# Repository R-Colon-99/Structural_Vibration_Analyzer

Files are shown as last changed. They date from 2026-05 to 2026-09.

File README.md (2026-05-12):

# Structural Vibration Analyzer

Low-cost multi-sensor structural vibration analysis platform using ESP32 and MEMS accelerometers for educational and experimental mechanical vibration studies.

---

# Overview

This project focuses on the development of a portable and affordable vibration-analysis system capable of measuring and analyzing structural vibration using low-cost MEMS accelerometers.

The system is designed primarily for:
- Mechanical vibration experimentation
- Educational laboratory use
- Structural response analysis
- Frequency-domain analysis using FFT
- Comparative sensor studies

The project currently uses multiple MPU6050 accelerometers connected to an ESP32 microcontroller through a PCA9548A I2C multiplexer.

---

# Objectives

- Develop a low-cost vibration analysis platform
- Measure structural vibration at multiple locations simultaneously
- Perform FFT analysis on acceleration data
- Compare structural vibration transmission between locations
- Investigate the limitations of low-cost MEMS sensors
- Create an accessible educational platform for vibration analysis

---

# Current Features

- ESP32-based data acquisition
- Support for 3 simultaneous MPU6050 sensors
- PCA9548A I2C multiplexer integration
- Binary serial data transmission
- Python-based logger and analyzer
- FFT analysis for X, Y, and Z axes
- Comparative FFT overlays between sensors
- Automatic graph generation and export
- Organized raw and processed data workflow

---

# Experimental Setup

Three accelerometers are mounted at different structural locations:

| Sensor | Location |
|---|---|
| S1 | Printer base/frame |
| S2 | Upper structural frame |
| S3 | Print head/extruder |

All sensors are rigidly mounted using screw-fastened brackets to improve measurement consistency and reduce mounting-induced vibration artifacts.

The current primary test platform is an Elegoo Centauri Carbon 3D printer.

---

# Hardware Used

- ESP32 Development Board
- MPU6050 Accelerometers (x3)
- PCA9548A I2C Multiplexer
- Rigid sensor mounting brackets
- USB Serial Communication
- Optional MicroSD module (future integration)

---

# Software Stack

- PlatformIO
- VS Code
- Python
- NumPy
- Matplotlib
- PySerial

---

# Future Work

- SD card standalone logging
- Wireless monitoring interface
- Higher-rate acquisition systems
- ADXL355 sensor integration
- Modal analysis implementation
- Natural frequency estimation tools
- Comparison with industrial accelerometers
- Real-time web dashboard visualization

---

# Author

Raúl Colón  
Mechanical Engineering Student  
Universidad Ana G. Méndez

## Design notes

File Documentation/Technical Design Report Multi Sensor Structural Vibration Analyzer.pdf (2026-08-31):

### Technical Design Report: Multi-Sensor Structural Vibration Analyzer

1. Executive Summary
In the domain of structural health monitoring (SHM), high-precision vibration analysis is the cornerstone of life-cycle assessment for critical infrastructure. Modern engineering demands high-fidelity data to detect infinitesimal modal shifts in bridges and industrial assets before they progress to catastrophic failure. This report outlines a hardware architecture that achieves professional-grade results—comparable to costly, proprietary DAQ systems—by utilizing a highly integrated, cost-effective embedded ecosystem. By shifting the paradigm from expensive centralized hardware to distributed, scalable sensing nodes, this architecture democratizes real-time frequency-domain analysis.The system synthesizes the computational power of the ESP32 System-on-Chip (SoC) with an array of MPU-6050 Micro-Electro-Mechanical Systems (MEMS) sensors. To overcome the physical limitations of I2C address bus contention, the design incorporates a TCA9548A/PCA9548A multiplexer, allowing the controller to interface with up to eight independent sensor nodes. The core operational objective is the maintenance of a deterministic, high-speed raw data stream to a host computer. By offloading the computationally intensive Fast Fourier Transform (FFT) to a host environment, the embedded system remains focused on precise temporal alignment and signal integrity, providing a blueprint for modern structural diagnostics.
2. Hardware Architecture & System Integration
The efficacy of a structural analyzer is dictated by its ability to resolve timing at the microsecond level while managing substantial data throughput. Selecting components that balance high-speed internal buffering with robust communication protocols is essential to meet the rigorous sampling requirements of civil engineering applications.

The ESP32 Processing Core
The heart of the system is the ESP32 Series SoC, featuring the Xtensa® 32-bit dual-core LX6 microprocessor. Running at a clock frequency of 240 MHz, this dual-core architecture is strategically utilized through "Core Pinning." In this configuration, the sampling Interrupt Service Routine (ISR) is pinned to Core 1 to ensure deterministic I2C polling, while Core 0 handles the non-deterministic overhead of the Wi-Fi or Bluetooth v4.2 (including BR/EDR and Bluetooth LE) stacks.
- Memory and Throughput: The 520 KB on-chip SRAM facilitates large sample buffers, which are essential for preventing data loss during burst transmissions. The system utilizes dedicated memory access pathways and the ESP32’s internal bus architecture to move data from the I2C peripheral to SRAM with minimal CPU intervention, maximizing the cycles available for real-time conditioning.
- Power Domain Configuration: To ensure logic level compatibility with the sensing array, the internal LDO (VDD_SDIO) must be configured for 3.3V operation. This is achieved by ensuring the MTDI strapping pin is held LOW (0) during the boot sequence, aligning the VDD_SDIO power domain with the VDD3P3_RTC voltage.

MPU-6050 Inertial Measurement Unit
The MPU-6050 provides 6-axis motion tracking, integrating a 3-axis accelerometer and a 3-axis gyroscope. For structural monitoring, the sensor’s 1024-byte FIFO buffer is a critical asset; it allows for continuous data accumulation even when the I2C bus is temporarily
occupied by the multiplexer switching logic.| Accelerometer Range | Sensitivity (LSB/g) |
Primary Application || ------ | ------ | ------ || ±2g | 16,384 | Seismic & Modal Bridge Analysis ||
±4g | 8,192 | General Structural Monitoring || ±8g | 4,096 | Industrial Machinery Diagnostics ||
±16g | 2,048 | High-Impact Event Recording || I2C Address | 0x68 | Base Address |

I2C Bus Expansion via TCA9548A / PCA9548A
The TCA9548A multiplexer resolves the address conflicts of the sensing array by providing eight bidirectional translating channels. Supporting I2C speeds up to 400 kHz, the multiplexer allows the ESP32 to cycle through sensors by writing a single byte to the control register. A vital engineering detail for long-term deployments on large assets like bridges is the "active LOW" hardware RESET function. This physical reset line allows the ESP32 to recover the I2C bus from stalls caused by Electromagnetic Interference (EMI) or signal degradation over long wire runs without requiring a full system power cycle. While the system supports 400 kHz Fast Mode, actual throughput is carefully tuned to account for the SDA pull-up strength constraints inherent in the ESP32 I2C peripheral.This integrated hardware stack provides the raw high-fidelity data required for advanced digital signal conditioning and noise isolation.
3. Signal Conditioning & Digital Low-Pass Filtering (DLPF)
Isolating relevant structural frequencies from high-frequency environmental and electronic noise is a prerequisite for valid spectral analysis. The Digital Low-Pass Filter (DLPF) within the MPU-6050 serves as the primary hardware-level conditioning stage, ensuring that only the target signal band enters the processing pipeline.

DLPF Register Logic
The filter is configured via the DLPF_CFG2:0 bits in the CONFIG register (Address 1A hex). Enabling the DLPF fundamentally alters the sensor’s internal dynamics: while the gyroscope’s internal sampling rate drops from 8 kHz to 1 kHz, the accelerometer maintains a fixed 1 kHz internal sample rate. This synchronization at 1 kHz across all axes simplifies the firmware’s timing logic and provides a stable base for anti-aliasing.

Filter Characteristics Table
DLPF Setting,Accel Bandwidth (Hz),Gyro Bandwidth (Hz),Group Delay (ms) 0,260,256,0.0
1,184,188,2.0
2,94,98,3.0
3,44,42,4.9
4,21,20,8.5
5,10,10,13.8
6,5,5,19.0
From a research perspective, the "Group Delay" is a critical parameter. At the narrowest setting (5 Hz), the 19.0 ms delay must be mathematically accounted for in the timestamping of the data. This delay is particularly significant if the analyzer is integrated into an active structural damping system, where excessive phase lag in the feedback loop can lead to control instability.These internal sensor configurations define the signal's purity and temporal characteristics before the data is transmitted for final frequency-domain processing.
4. Signal Processing Analysis: Bandwidth vs. FFT Performance
The conversion of physical motion into a meaningful digital frequency spectrum is governed by the Nyquist-Shannon sampling theorem. Proper alignment between the physical sampling rate and the hardware filter bandwidth is the only way to ensure the validity of the resulting FFT.

Nyquist Criteria & Anti-Aliasing
With the accelerometer's internal sampling rate fixed at 1 kHz, the Nyquist frequency is established at 500 Hz. To prevent aliasing—where high-frequency noise is mathematically folded back into the low-frequency spectrum—the DLPF must be used as a front-end anti-aliasing filter. Selecting a bandwidth of 184 Hz or 94 Hz ensures that signal components near or above 500 Hz are significantly attenuated before they are digitized, preserving the integrity of the structural data.

Noise Floor Optimization
Structural assets like bridge decks often exhibit dominant frequencies below 10 Hz. In these scenarios, selecting narrow bandwidths (e.g., 10 Hz or 5 Hz) dramatically improves the Signal-to-Noise Ratio (SNR) by filtering out ambient high-frequency jitter. This optimization of the noise floor is what allows the system to resolve the subtle modal signatures necessary for early-stage fatigue detection.

ESP32 Firmware Sampling Strategy
To maintain FFT accuracy on the host PC, the ESP32 must adhere to a rigid, deterministic sampling interval.
- 1 kHz Synchronization: The firmware must poll the sensor array at exactly 1 kHz (or integer divisions thereof).
- The "Stair-Step" Phenomenon: If the ESP32 polls the I2C bus faster than the internal 1 kHz update rate of the sensor, it will ingest duplicate data points. In the time domain, this manifests as "stair-step" distortion, which creates significant spectral artifacts and "ghost" frequencies in the final FFT. By pinning the I2C task to a dedicated core and utilizing high-resolution hardware timers, the system ensures that every sample represents a unique and accurately timed physical event.The synthesis of dual-core deterministic processing, hardware-level anti-aliasing, and robust I2C bus management establishes this architecture as a high-performance blueprint for the next generation of structural vibration analysis.

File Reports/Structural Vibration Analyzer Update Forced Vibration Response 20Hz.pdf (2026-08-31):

# Structural Vibration Analyzer Project Experimental Update Report – Forced Vibration Test at 20 Hz

Ra´ul Col´on

May 12, 2026

## 1 Introduction

This report presents an updated analysis of vibration data collected using the current Structural Vibration Analyzer setup. The system uses an ESP32 microcontroller, a PCA9548A I2C multiplexer, and three MPU6050 accelerometers. The objective of this test was to evaluate the vibration behavior of a 3D printer structure under a forced vibration condition of approximately:

fforcing = 20 Hz

The three sensors were mounted as follows:

- Sensor 1 (s1): mounted at the base/frame region.
- Sensor 2 (s2): mounted on the upper/opposite side of the frame.
- Sensor 3 (s3): mounted on the printer head/extruder assembly.

All sensors were mounted using rigid screw-mounted fixtures. This was done to reduce unwanted movement between the sensor and the structure and to improve the reliability of the measured vibration response.

## 2 Sampling Quality

The data was collected for approximately 92.629 seconds with 74,103 samples. The estimated sampling rate was:

fs = 799.99 Hz

The Nyquist frequency is therefore:

fN =

fs
2

= 399.99 Hz

This means the FFT results are valid up to approximately 400 Hz.

Parameter | Value
Estimated sampling rate | 799.99 Hz
Mean sampling interval | 0.00125002 s
Minimum sampling interval | 0.00121200 s
Maximum sampling interval | 0.00249900 s
Sampling interval standard deviation | 0.00000465 s
Duration | 92.629 s
Number of samples | 74103
Nyquist frequency | 399.99 Hz
Estimated dropped samples | 1
Repeated or reversed sample indices | 0

Table 1: Sampling quality summary.

## 3 Time-Domain Results

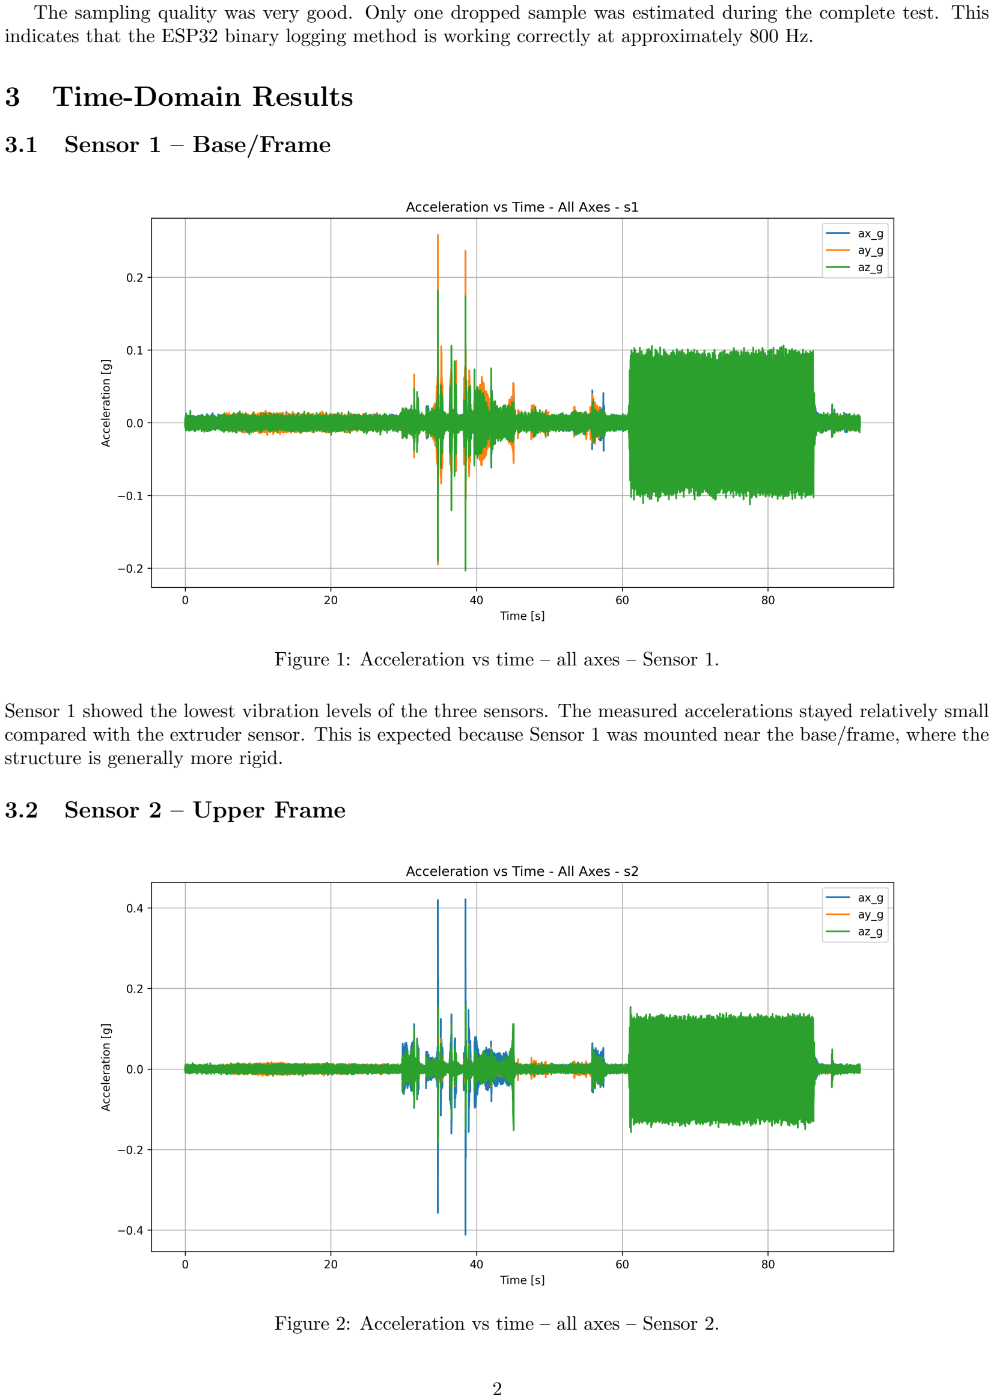
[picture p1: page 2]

The sampling quality was very good. Only one dropped sample was estimated during the complete test. This indicates that the ESP32 binary logging method is working correctly at approximately 800 Hz.

### 3.1 Sensor 1 – Base/Frame

Figure 1: Acceleration vs time – all axes – Sensor 1.

Sensor 1 showed the lowest vibration levels of the three sensors. The measured accelerations stayed relatively small compared with the extruder sensor. This is expected because Sensor 1 was mounted near the base/frame, where the structure is generally more rigid.

### 3.2 Sensor 2 – Upper Frame

Figure 2: Acceleration vs time – all axes – Sensor 2.

Sensor 2 showed larger vibration amplitudes than Sensor 1. This suggests that the upper frame region is more flexible and experiences more vibration amplification than the base.

### 3.3 Sensor 3 – Extruder

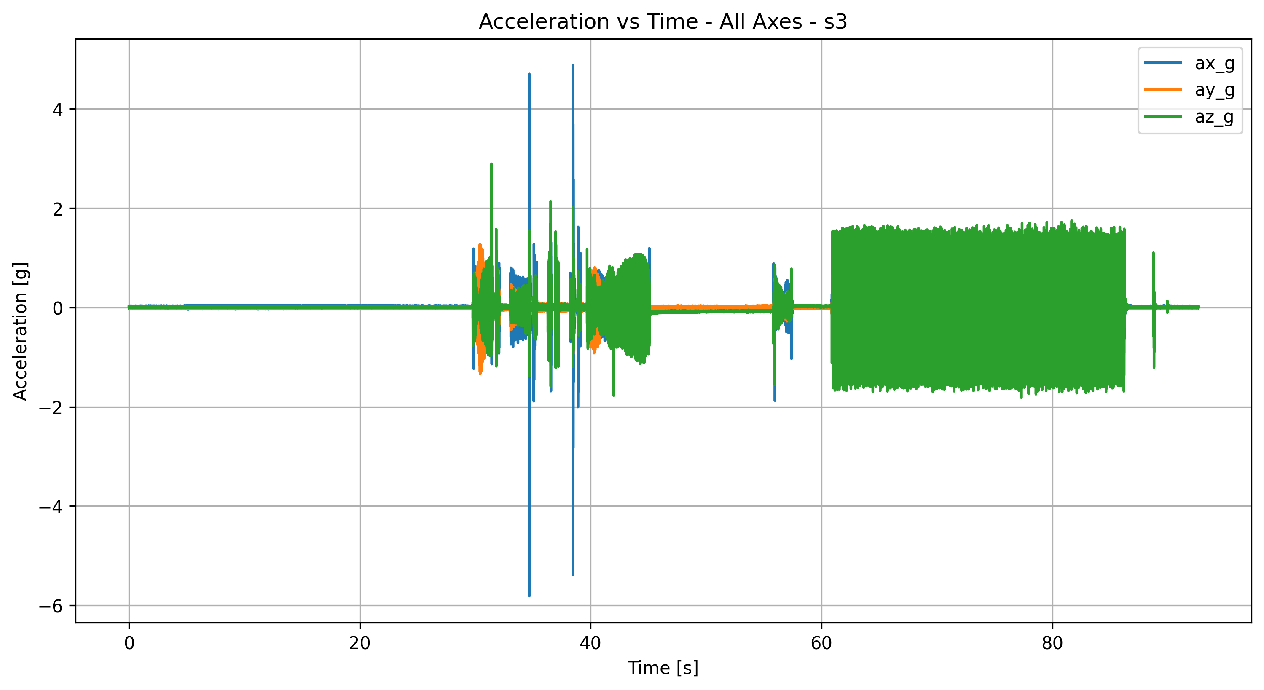
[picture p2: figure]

Figure 3: Acceleration vs time – all axes – Sensor 3.

Sensor 3 showed the largest vibration response. This is expected because the extruder is the moving component of the printer and is directly affected by motor motion, belt motion, inertia, and direction changes.
The largest measured peak acceleration was found in the X-axis of Sensor 3:

apeak = 5.815946g

The peak-to-peak acceleration for this same axis was:

ap−p = 10.692871g

This indicates that the extruder assembly is the most dynamically active part of the system.

## 4 FFT Method

The Fast Fourier Transform was used to convert the acceleration signal from the time domain into the frequency domain. The FFT allows the dominant vibration frequencies to be identified.
The general form of the discrete Fourier transform is:

Xk =

N

X⁻¹

n=0

xne

−j2πkn/N

where:

- xn is the acceleration signal in the time domain,
- Xk is the frequency-domain result,
- N is the number of samples,
- k is the frequency bin index.

## 5 FFT Results by Sensor

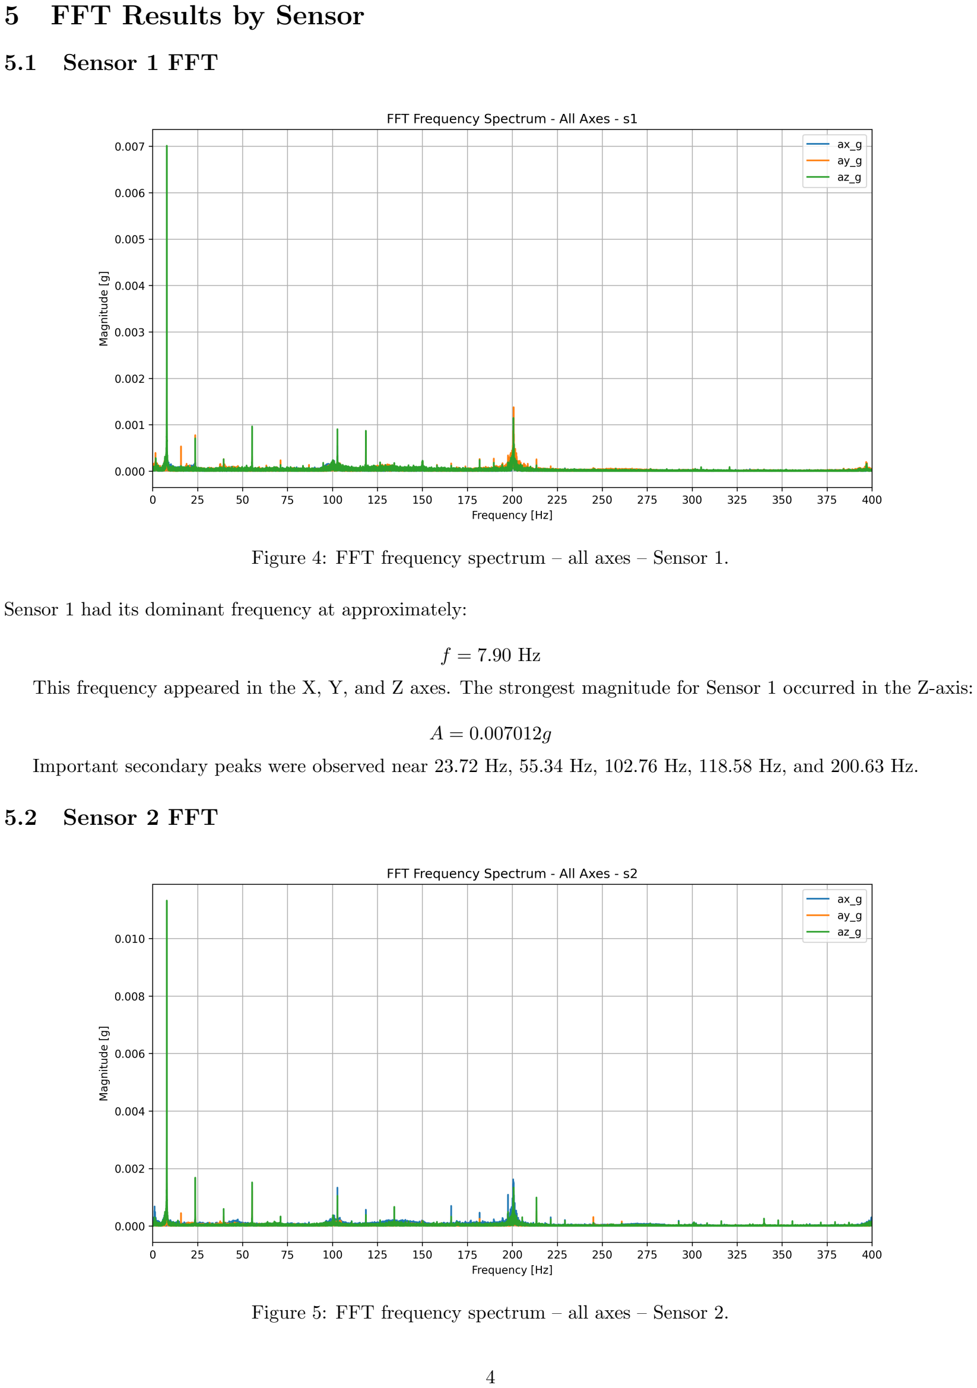
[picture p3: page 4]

### 5.1 Sensor 1 FFT

Figure 4: FFT frequency spectrum – all axes – Sensor 1.

Sensor 1 had its dominant frequency at approximately:

f = 7.90 Hz

This frequency appeared in the X, Y, and Z axes. The strongest magnitude for Sensor 1 occurred in the Z-axis:

A = 0.007012g

Important secondary peaks were observed near 23.72 Hz, 55.34 Hz, 102.76 Hz, 118.58 Hz, and 200.63 Hz.

### 5.2 Sensor 2 FFT

Figure 5: FFT frequency spectrum – all axes – Sensor 2.

Sensor 2 also showed a dominant frequency near:

f = 7.90 Hz

The strongest Sensor 2 response occurred in the Z-axis:

A = 0.011320g

This shows that the upper frame has a stronger vibration response than the base, especially in the vertical direction.

### 5.3 Sensor 3 FFT

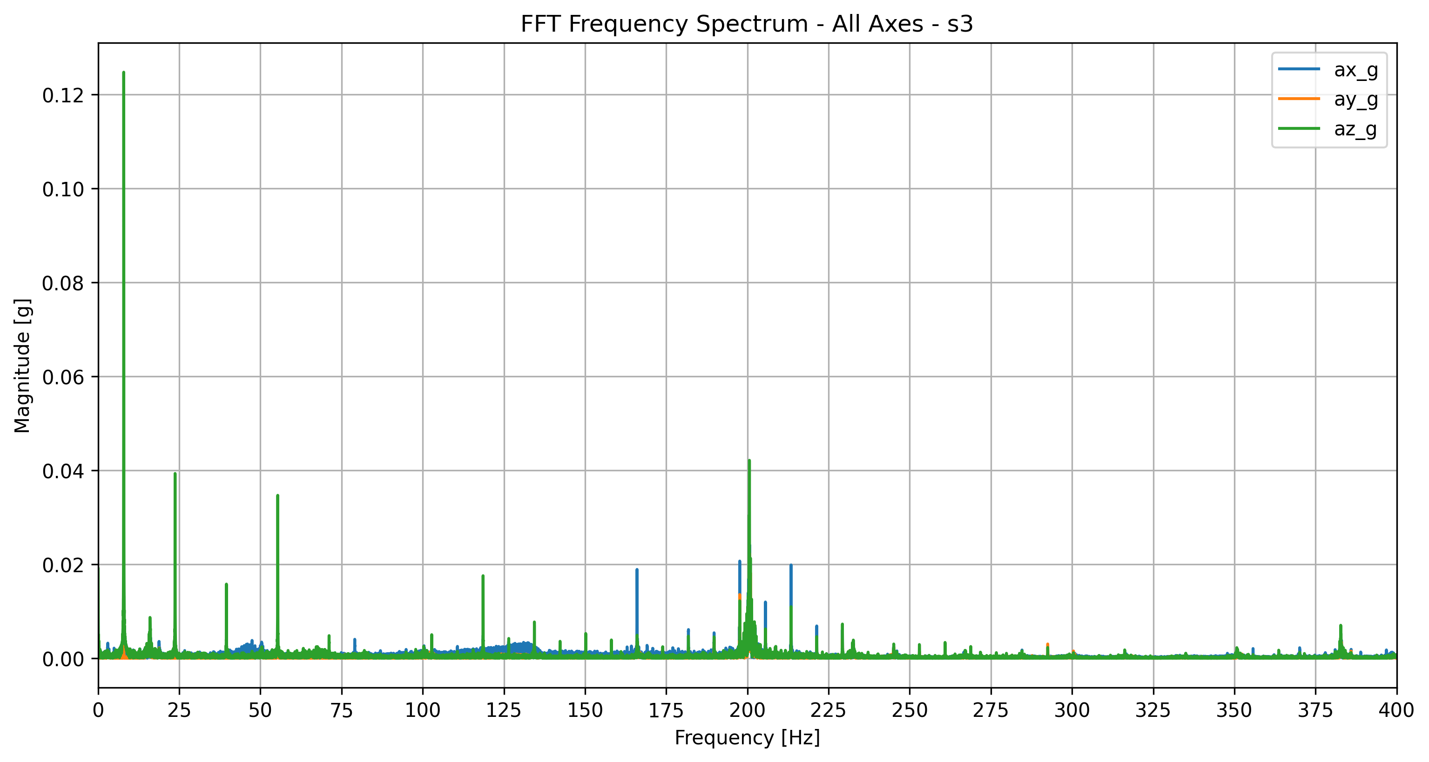
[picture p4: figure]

Figure 6: FFT frequency spectrum – all axes – Sensor 3.

Sensor 3 showed the largest FFT magnitudes. Two major frequency regions were observed:

- A low-frequency response near 7.90 Hz.
- A high-frequency response near 200 Hz.

The strongest overall FFT peak occurred in Sensor 3 Z-axis:

f = 7.90 Hz

A = 0.124771g

Sensor 3 X and Y axes had their dominant frequencies near 200 Hz:

fs3,x = 200.70 Hz

fs3,y = 200.64 Hz

This suggests that the extruder assembly has strong high-frequency vibration components, likely related to motor excitation, belt dynamics, or local print-head vibration.

## 6 Overlapped FFT Comparison

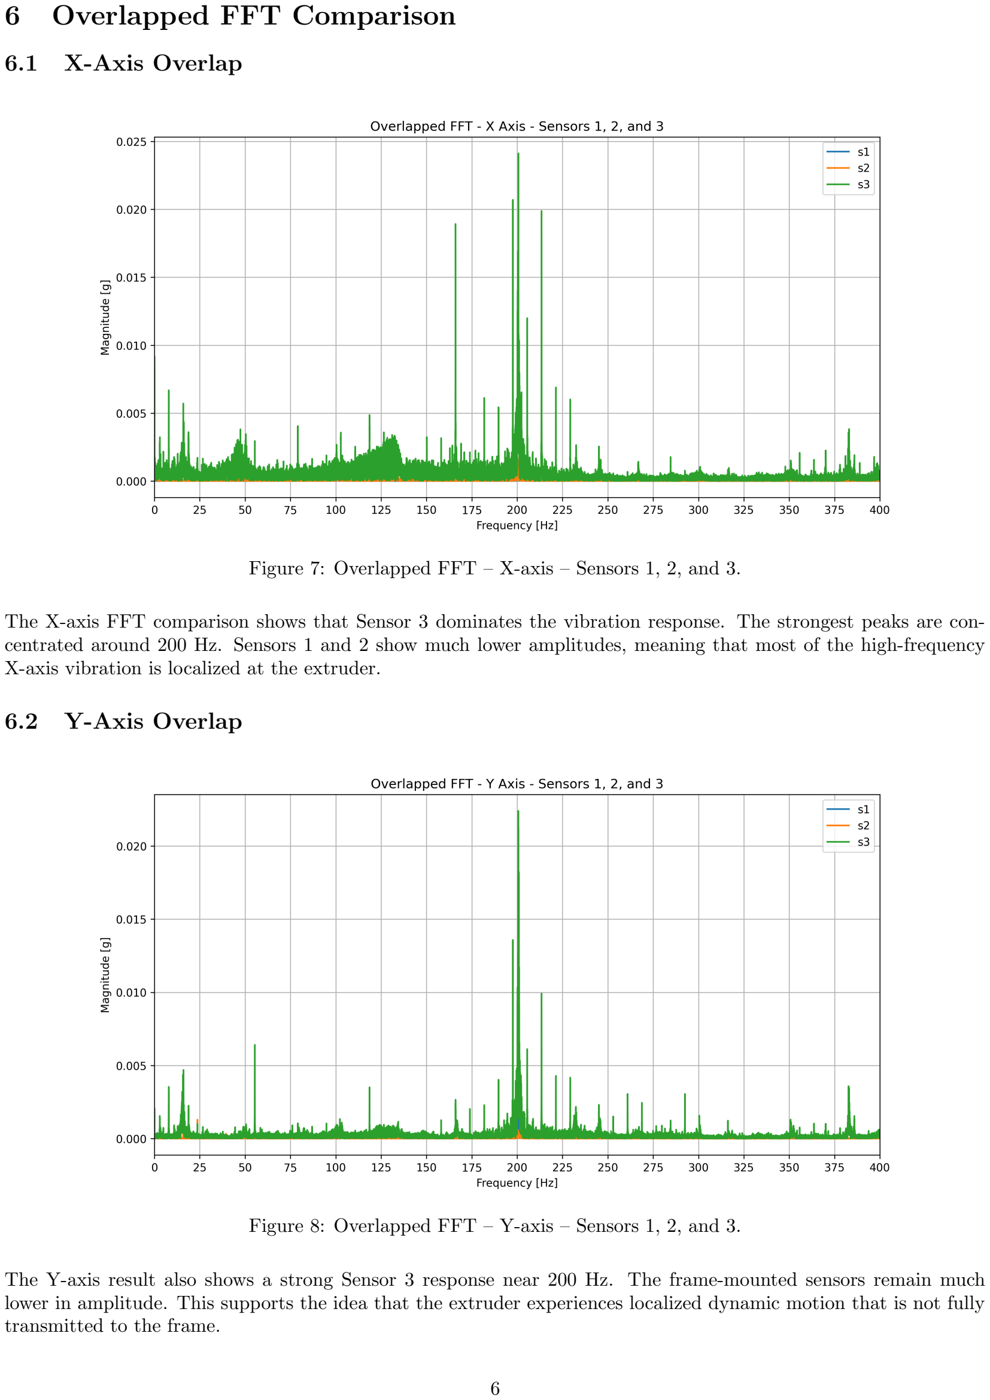
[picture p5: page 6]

### 6.1 X-Axis Overlap

Figure 7: Overlapped FFT – X-axis – Sensors 1, 2, and 3.

The X-axis FFT comparison shows that Sensor 3 dominates the vibration response. The strongest peaks are concentrated around 200 Hz. Sensors 1 and 2 show much lower amplitudes, meaning that most of the high-frequency X-axis vibration is localized at the extruder.

### 6.2 Y-Axis Overlap

Figure 8: Overlapped FFT – Y-axis – Sensors 1, 2, and 3.

The Y-axis result also shows a strong Sensor 3 response near 200 Hz. The frame-mounted sensors remain much lower in amplitude. This supports the idea that the extruder experiences localized dynamic motion that is not fully transmitted to the frame.

### 6.3 Z-Axis Overlap

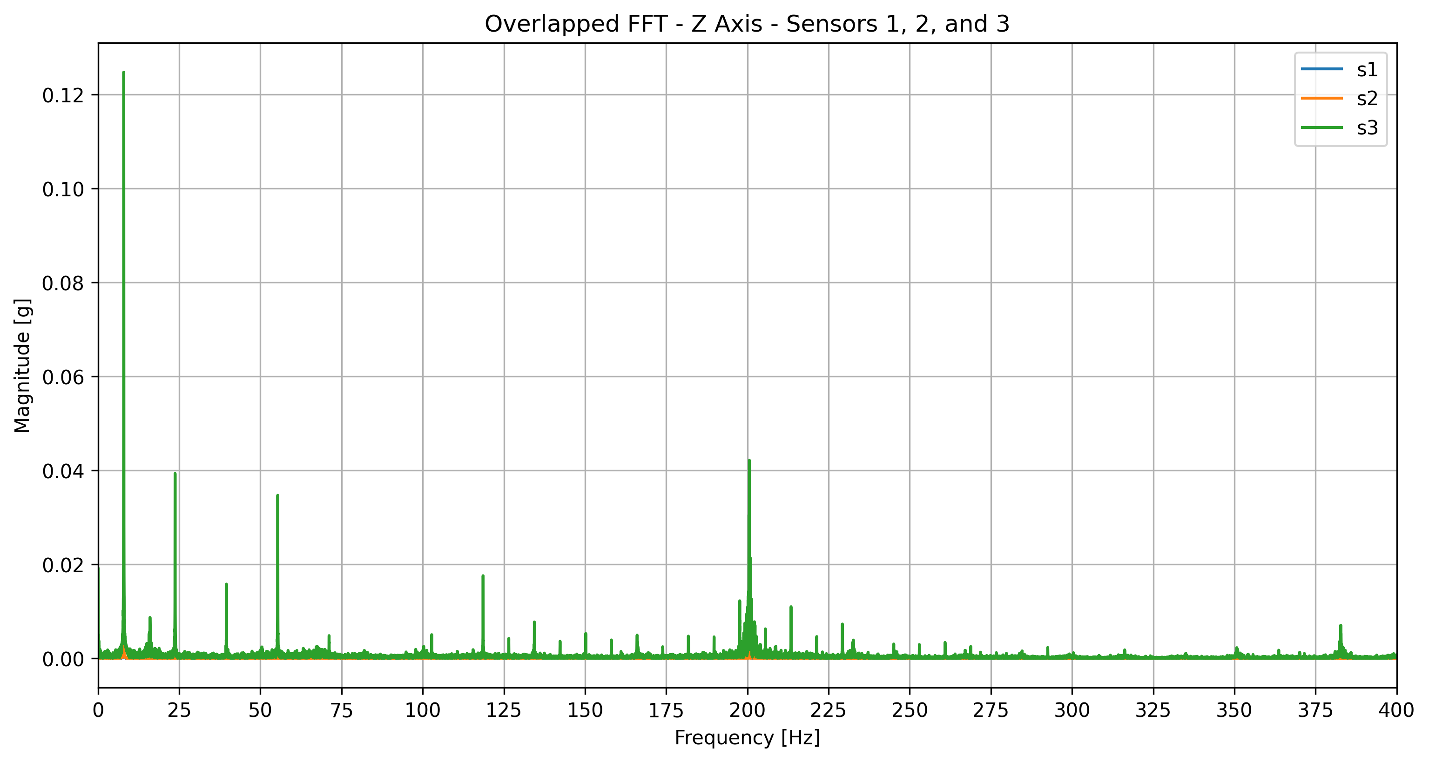
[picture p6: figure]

Figure 9: Overlapped FFT – Z-axis – Sensors 1, 2, and 3.

The Z-axis showed the largest overall vibration amplitude. The largest peak occurred near 7.90 Hz at Sensor 3. This suggests that the vertical direction is strongly affected by a low-frequency structural mode.

## 7 Interpretation of the 20 Hz Forced Vibration Test

Although the test was performed with a forced vibration input of approximately:

20 Hz

the dominant frequency response did not occur exactly at 20 Hz. Instead, the strongest responses occurred near:

7.90 Hz

and:

200 Hz

This does not necessarily mean the test failed. A mechanical structure does not always respond most strongly at the applied forcing frequency. If the forcing excites a natural mode of the structure, the response may be larger at the natural frequency than at the input frequency.
The peak near 23.72 Hz is close to the intended 20 Hz forcing frequency and likely represents the direct forced response or a nearby excitation component. However, the much stronger 7.90 Hz and 200 Hz peaks suggest that the structure is amplifying other modes.
Possible explanations include:
- The printer has a low-frequency structural mode near 8 Hz.
- The extruder or gantry has a high-frequency local mode near 200 Hz.
- The 20 Hz input may be exciting harmonics or coupled structural modes.
- The printer motion system may introduce additional frequencies through motor steps, belts, or control behavior.

## 8 Summary of Main FFT Results

Sensor/Axis | Dominant Frequency [Hz] | Magnitude [g] | RMS [g]
s1 X | 7.90 | 0.002297 | 0.010601
s1 Y | 7.90 | 0.002676 | 0.014357
s1 Z | 7.90 | 0.007012 | 0.027100
s2 X | 7.90 | 0.002497 | 0.017143
s2 Y | 7.90 | 0.003126 | 0.015194
s2 Z | 7.90 | 0.011320 | 0.043078
s3 X | 200.70 | 0.024116 | 0.211068
s3 Y | 200.64 | 0.022395 | 0.140092
s3 Z | 7.90 | 0.124771 | 0.533090

Table 2: Main FFT and RMS results by sensor and axis.

## 9 Acceleration Transmissibility

Acceleration transmissibility was calculated using Sensor 3 as the reference input because it was mounted on the extruder. Sensors 1 and 2 were treated as response sensors mounted on the frame.

| T = Aresponse
| Aref erence

where:

- Aresponse is the FFT magnitude measured at Sensor 1 or Sensor 2,
- Aref erence is the FFT magnitude measured at Sensor 3.

### 9.1 X-Axis Transmissibility

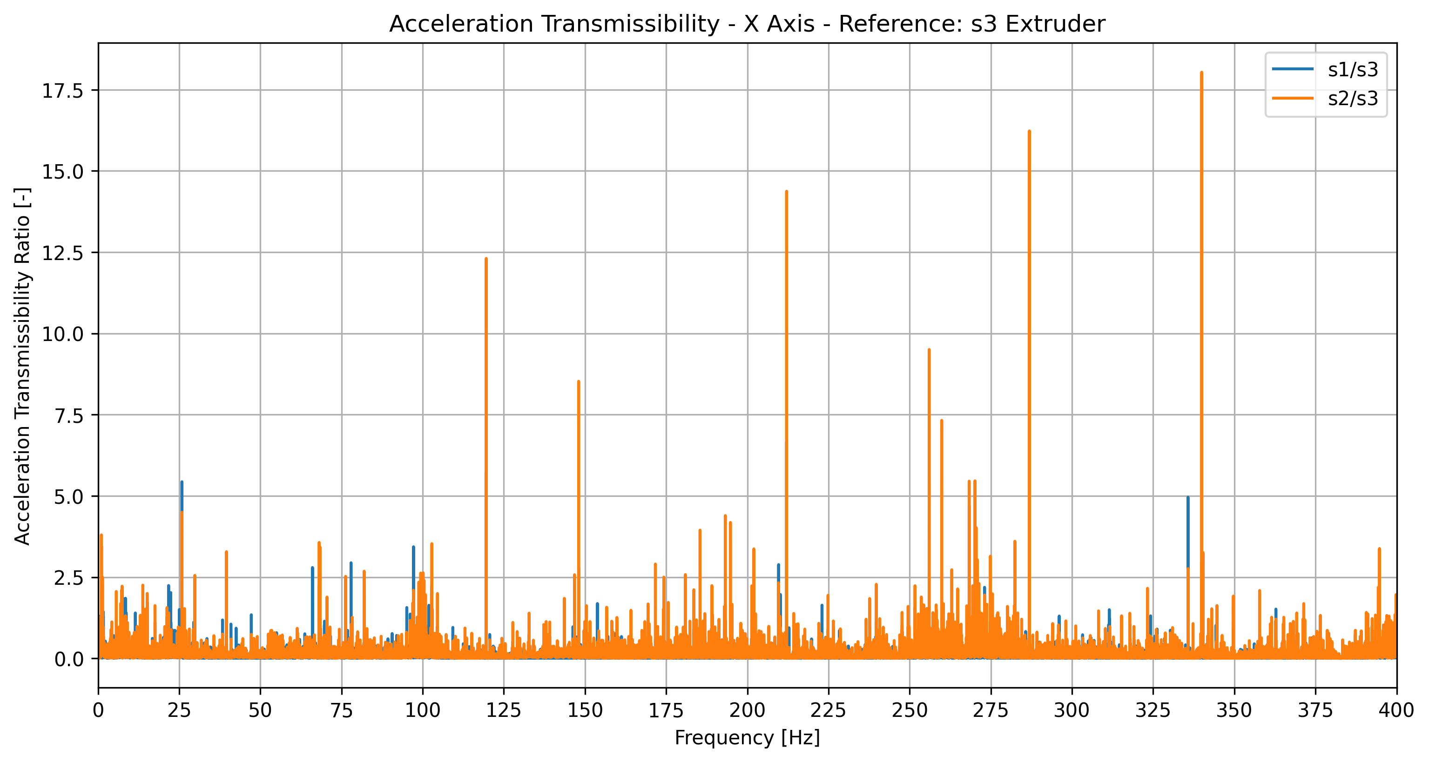
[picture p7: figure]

Figure 10: Acceleration transmissibility – X-axis – reference Sensor 3.

The X-axis transmissibility was generally below 1 for most frequencies. This means that most X-axis vibration measured at the extruder was attenuated before reaching the frame.

### 9.2 Y-Axis Transmissibility

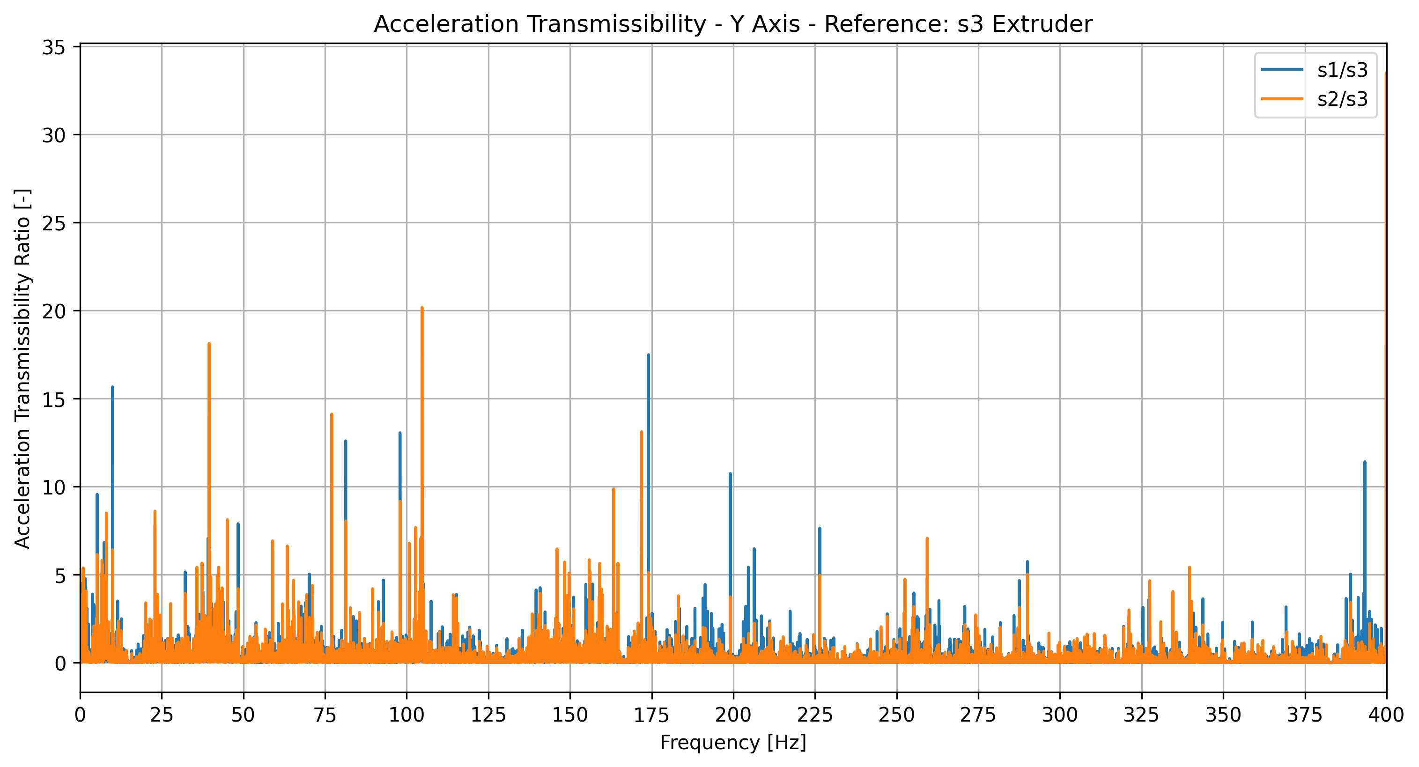
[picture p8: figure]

Figure 11: Acceleration transmissibility – Y-axis – reference Sensor 3.

The Y-axis transmissibility showed several sharp peaks. Some high transmissibility values occurred near the high-frequency end of the spectrum. These peaks may represent localized frame amplification or may occur when the reference signal from Sensor 3 is very small at certain frequencies.

### 9.3 Z-Axis Transmissibility

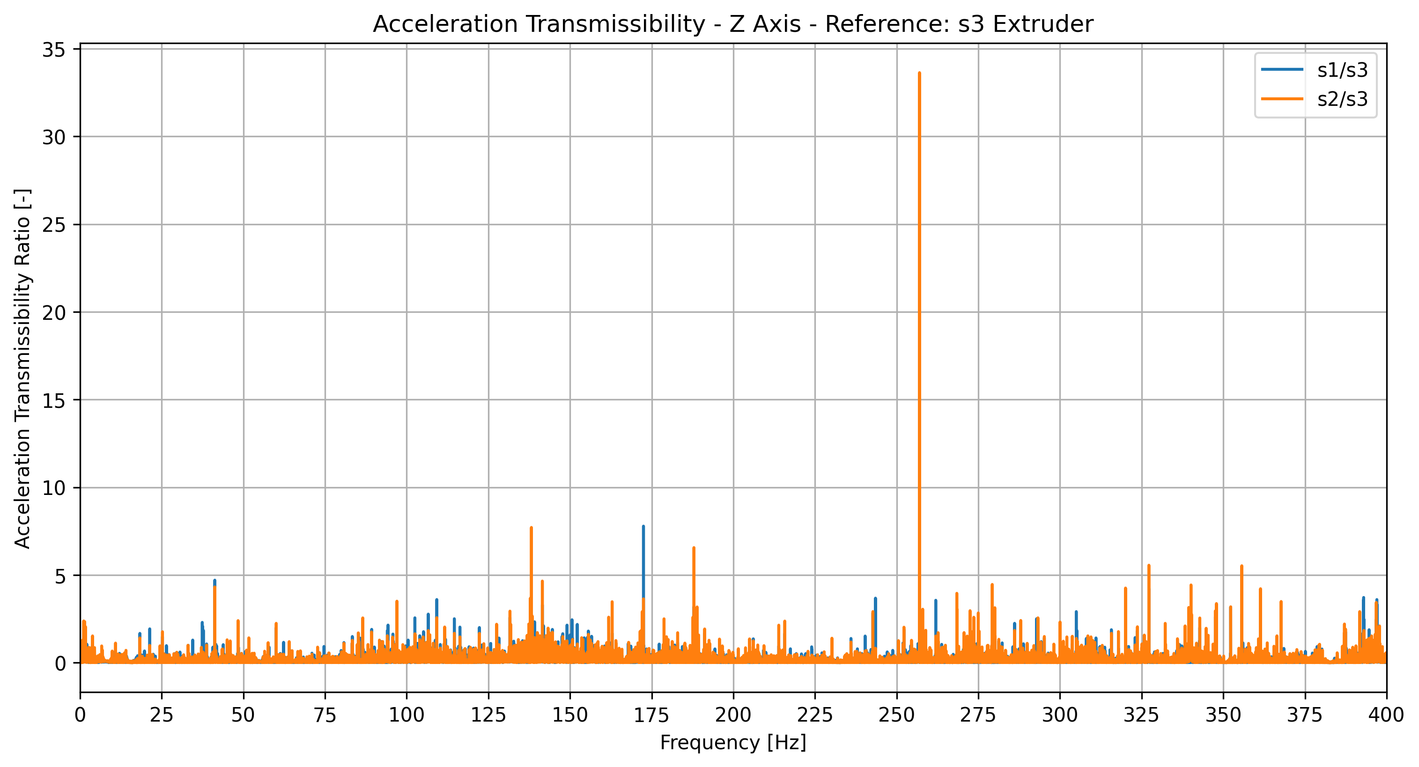
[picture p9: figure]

Figure 12: Acceleration transmissibility – Z-axis – reference Sensor 3.

The Z-axis transmissibility also showed sharp localized peaks. However, for most of the frequency range, the frame sensors remained lower than the extruder response. This indicates that the strongest vertical vibration remains concentrated at the extruder.

## 10 Transmissibility Summary

Ratio | Maximum T | Frequency [Hz] | Mean T
s1/s3 X | 6.6584 | 212.09 | 0.0680
s2/s3 X | 18.0361 | 339.94 | 0.1296
s1/s3 Y | 18.0409 | 399.86 | 0.2134
s2/s3 Y | 33.5188 | 399.86 | 0.1882
s1/s3 Z | 12.2423 | 256.99 | 0.1060
s2/s3 Z | 33.6335 | 256.99 | 0.1292

Table 3: Acceleration transmissibility summary.

The average transmissibility values are all below 1. This means the frame generally receives less vibration than the extruder. However, the maximum transmissibility values are much larger than 1 at specific frequencies. These isolated peaks require further study because they may correspond to structural resonances or numerical effects caused by low reference amplitude.

## 11 Key Observations

1. The ESP32-based system successfully collected data at approximately 800 Hz.
2. The sampling quality was stable, with only one estimated dropped sample.
3. The dominant low-frequency structural response appeared near 7.90 Hz.
4. The extruder showed strong high-frequency vibration near 200 Hz.
5. Sensor 3 had much larger vibration amplitudes than Sensors 1 and 2.
6. The Z-axis produced the strongest low-frequency response.
7. The forced 20 Hz excitation was visible near 23.72 Hz, but it was not the dominant response.
8. The frame attenuated most of the vibration coming from the extruder, except at isolated frequencies.

## 12 Conclusions

The updated vibration test shows that the low-cost ESP32 and MPU6050-based system is capable of identifying meaningful vibration behavior in a 3D printer structure.
The main finding is that the printer does not respond most strongly at the applied 20 Hz forcing frequency. Instead, the structure appears to amplify vibration near 7.90 Hz and near 200 Hz.
The 7.90 Hz response likely represents a low-frequency structural mode of the printer. The 200 Hz response appears to be strongly localized at the extruder and may be related to the motion system, motor excitation, belt behavior, or local print-head vibration.
The transmissibility analysis shows that most vibration is attenuated as it travels from the extruder to the frame. However, sharp transmissibility peaks suggest that there are specific frequencies where the frame may amplify vibration.
Overall, the results support the continued development of this project as a low-cost structural vibration analysis platform for educational and experimental use.

## 13 Recommended Next Steps

- Repeat the test at different forced frequencies such as 2 Hz, 10 Hz, 50 Hz, 100 Hz, 150 Hz, and 200 Hz.
- Perform a controlled frequency sweep to better identify natural frequencies.
- Compare the MPU6050 results with a higher-quality accelerometer in the future.

- Add a band-limited transmissibility analysis to avoid misleading peaks caused by small denominator values.
- Investigate the strong 200 Hz response at the extruder.
- Improve the report plots by adding annotations for the 7.90 Hz, 20 Hz, 23.72 Hz, and 200 Hz regions.

## Source File

The numerical results used in this report were taken from:

summary V2.txt

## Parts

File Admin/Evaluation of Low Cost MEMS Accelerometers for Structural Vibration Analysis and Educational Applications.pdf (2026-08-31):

# Research Proposal

# Evaluation of Low-Cost MEMS Accelerometers for Structural Vibration Analysis and Educational Applications

### Raul Colon Mechanical Engineering Program Universidad Ana G. Mendez

### June 13, 2026

Abstract

Mechanical vibration analysis is a critical topic in engineering fields such as machine design, rotating machinery diagnostics, aerospace structures, manufacturing systems, and condition monitoring. Professional vibration measurement systems often require specialized accelerometers and data acquisition hardware that may be prohibitively expensive for educational institutions and student projects.
This research proposes the evaluation of the MPU6050 MEMS accelerometer as a low-cost alternative for vibration analysis applications. A structural vibration analyzer prototype has already been developed using three MPU6050 sensors, an ESP32 microcontroller, and custom Python-based signal processing software. The primary objective of this research is to experimentally determine the limitations, accuracy, and practical capabilities of the MPU6050 when compared to analytical predictions and, when available, professional vibration measurement equipment.
The project also seeks to investigate the potential use of low-cost vibration analyzers as educational tools in Mechanical Vibrations courses. The expected outcome is a validated assessment of the strengths and weaknesses of MEMS-based vibration measurement systems and recommendations regarding their suitability for engineering education and introductory vibration studies.

## Contents

1 Introduction | 3
2 Research Problem | 3
3 Research Objectives | 3
4 Research Questions | 4
5 Prototype Developed | 4
6 Research Methodology | 5
7 Educational Applications | 6
8 Future Improvements | 7
9 Expected Outcomes | 8
10 Expected Deliverables | 8
11 Conclusion | 9

## 1 Introduction

Mechanical vibration analysis is commonly used to identify natural frequencies, resonance conditions, structural response characteristics, and machinery faults. Traditionally, vibration studies rely on laboratory-grade instrumentation systems, including piezoelectric accelerometers and dedicated data acquisition hardware.
Recent advances in Micro-Electro-Mechanical Systems (MEMS) have resulted in the availability of inexpensive accelerometers such as the MPU6050. Although these sensors are widely used in robotics, drones, and motion sensing applications, their suitability for engineering vibration analysis remains an area of interest.
This project builds upon a structural vibration analyzer prototype previously developed by the author. The system utilizes multiple MPU6050 accelerometers, an ESP32 microcontroller, and Python-based Fast Fourier Transform (FFT) analysis tools to measure structural vibrations.
The proposed research seeks to quantify the capabilities and limitations of this low-cost system and determine whether such a platform can serve as a viable educational tool for undergraduate engineering courses.

## 2 Research Problem

Commercial vibration analysis systems are often costly and inaccessible to many educational institutions and students.
Although low-cost MEMS accelerometers offer an attractive alternative, questions remain regarding:
- Measurement accuracy
- Frequency range limitations
- Noise characteristics
- Sensitivity to low-amplitude vibrations
- Ability to identify natural frequencies
- Repeatability and reliability

Currently, limited information is available regarding the practical use of MPU6050 sensors for engineering vibration analysis applications.

## 3 Research Objectives

### 3.1 Primary Objective

Determine the limitations and practical capabilities of the MPU6050 accelerometer for structural vibration analysis.

### 3.2 Secondary Objectives

1. Develop controlled vibration experiments using structures with analytically predictable behavior.
2. Compare measured natural frequencies against theoretical calculations.
3. Evaluate measurement repeatability and consistency.
4. Quantify sensor noise and frequency resolution limitations.
5. Investigate the effects of sensor placement and sensor mass loading.
6. Compare results with professional instrumentation when available.
7. Develop laboratory procedures suitable for undergraduate engineering education.
8. Assess the feasibility of implementing low-cost vibration analyzers in Mechanical Vibrations and Experimental Methods courses.

## 4 Research Questions

1. Can an MPU6050 accurately identify structural natural frequencies?
2. What frequency range can be reliably measured?
3. What is the minimum vibration amplitude that can be detected?
4. How repeatable are measurements obtained from MPU6050 sensors?
5. How closely do measured frequencies match analytical predictions?
6. Can low-cost vibration analyzers provide educational value comparable to higher-cost laboratory equipment?

## 5 Prototype Developed

A functional structural vibration analyzer has already been developed.

### 5.1 Hardware

- ESP32 Development Board
- PCA9548A I2C Multiplexer
- Three MPU6050 Accelerometers
- USB Serial Communication Interface
- Custom Sensor Mounting Fixtures
- Desktop Computer for Data Processing

### 5.2 Software

- ESP32 Firmware (C++)
- Python Data Logger
- Python FFT Analysis Software
- NumPy
- SciPy
- Pandas
- Matplotlib

### 5.3 Current Capabilities

The current prototype can:

- Acquire vibration data from up to three accelerometers simultaneously.
- Record synchronized acceleration measurements.
- Export vibration data to CSV format.
- Perform Fast Fourier Transform analysis.
- Generate frequency-domain plots.
- Compare vibration responses at multiple locations.

## 6 Research Methodology

### 6.1 Phase I: Analytical Validation

Simple structures with known analytical solutions will be used. Examples include:

- Cantilever beams
- Mass-Spring

Theoretical natural frequencies will be calculated.
Measured frequencies will then be compared with analytical predictions.

### 6.2 Phase II: Experimental Validation

Controlled vibration tests will be conducted.
Methods may include:
- Impact hammer testing
- Free vibration decay
- Speaker-induced vibration

Data will be collected using the developed analyzer.

### 6.3 Phase III: Repeatability Analysis

Repeated experiments will be performed to evaluate:

- Frequency measurement consistency
- Amplitude consistency
- FFT peak stability

### 6.4 Phase IV: Comparative Validation

When professional equipment becomes available, direct comparisons will be performed. Potential comparison systems include:

- National Instruments DAQ systems
- LabVIEW-based vibration systems
- Industrial accelerometers
- Piezoelectric vibration sensors

## 7 Educational Applications

One of the motivations for this research is the potential use of low-cost instrumentation within engineering education.
Possible laboratory activities include:
1. Determination of natural frequencies.
2. Experimental modal analysis demonstrations.
3. FFT signal analysis exercises.
4. Resonance investigations.

5. Vibration isolation experiments.
6. Beam vibration laboratories.
7. Data acquisition and signal processing instruction.

The resulting platform could provide students with hands-on experience at a fraction of the cost of traditional laboratory equipment.

## 8 Future Improvements

Several improvements are planned to expand the capabilities of the current prototype.

### 8.1 Hardware Improvements

- MicroSD data logging
- OLED user interface
- Rotary encoder control system
- Battery-powered operation
- Wireless communication
- Improved sensor mounting systems
- Alternative MEMS accelerometers
- Higher-performance accelerometers

### 8.2 Software Improvements

- Embedded FFT processing on ESP32
- More advanced microcontrollers
- Automated modal identification
- Improved filtering algorithms
- Data synchronization improvements
- Advanced transmissibility calculations
- Frequency response function estimation

### 8.3 Validation Improvements

- Comparison with laboratory-grade accelerometers
- Comparison with National Instruments systems
- Calibration procedures
- Uncertainty analysis
- Statistical error quantification

## 9 Expected Outcomes

The project is expected to produce:

1. A quantified assessment of MPU6050 vibration measurement capabilities.
2. Identification of measurement limitations.
3. Validation of the developed structural vibration analyzer.
4. Educational laboratory procedures.
5. Recommendations regarding the use of low-cost vibration instrumentation in engineering education.
6. A foundation for future research involving advanced accelerometer technologies.

## 10 Expected Deliverables

- Final research report
- Experimental test procedures
- Validation datasets
- FFT analysis software
- Structural vibration analyzer hardware
- Educational laboratory modules
- Recommendations for curriculum implementation

## 11 Conclusion

This research seeks to bridge the gap between low-cost sensor technology and engineering vibration analysis by evaluating the MPU6050 accelerometer in a controlled experimental environment. Through analytical validation, experimental testing, and future comparison with professional instrumentation, the project aims to establish the capabilities and limitations of MEMS-based vibration analyzers.
The results have the potential to contribute both to engineering education and to the development of affordable vibration analysis tools for academic institutions, student projects, and introductory research applications.

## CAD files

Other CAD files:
CAD/Fusion360_exports/mpu mount.f3d

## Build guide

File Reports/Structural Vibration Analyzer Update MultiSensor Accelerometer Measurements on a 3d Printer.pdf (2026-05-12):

# Structural Vibration Analysis Update Multi-Sensor Accelerometer Measurements on a 3D Printer

### Ra´ul Col´on

### May 11, 2026

## 1 Objective

The purpose of this experiment was to continue evaluating the feasibility of using low-cost MEMS accelerometers for structural vibration analysis applications. A three-sensor configuration was implemented to observe vibration transmission through different regions of the printer structure and to compare the dynamic response at each location.
This report serves as a progress update of the experimental setup, data acquisition process, and preliminary vibration analysis results obtained from the printer structure.

## 2 Experimental Setup

Three MPU6050 accelerometers were used simultaneously during the test. All sensors were mounted using rigid screw-mounted brackets directly attached to the printer structure in order to minimize mounting flexibility and measurement damping caused by adhesive or soft mounts.
The sensor locations were defined as follows:
- Sensor 1 (s1): Mounted at the base of the printer frame.
- Sensor 2 (s2): Mounted on the opposite side of the structure toward the upper section of the printer frame.
- Sensor 3 (s3): Mounted directly on the printer head/extruder assembly.

The use of multiple sensors allowed the observation of vibration propagation through the structure and enabled comparison between the rigid frame response and the motion occurring at the moving print head assembly.

## 3 Data Acquisition Parameters

The vibration data was collected using an ESP32-based acquisition system operating at a high sampling rate.

Table 1: Data Acquisition Parameters

Parameter | Value
Estimated Sampling Rate | 800 Hz
Sampling Interval | 0.00125 s
Total Duration | 16.714 s
Number of Samples | 13,372
Nyquist Frequency | 400 Hz
Data Mode | Three Sensor Mode

The sampling rate was selected to allow observation of structural frequencies up to approximately 400 Hz while maintaining sufficient temporal resolution for transient vibration events.

## 4 Time Domain Results

Figures 1, 2, and 3 show the acceleration response measured by each sensor in the time domain.
A transient excitation event can be observed near the 5-second mark in all sensors. The response shows a damped oscillatory behavior following the excitation, indicating structural vibration decay after the impulse event.

### 4.1 Sensor 1 – Base of Printer

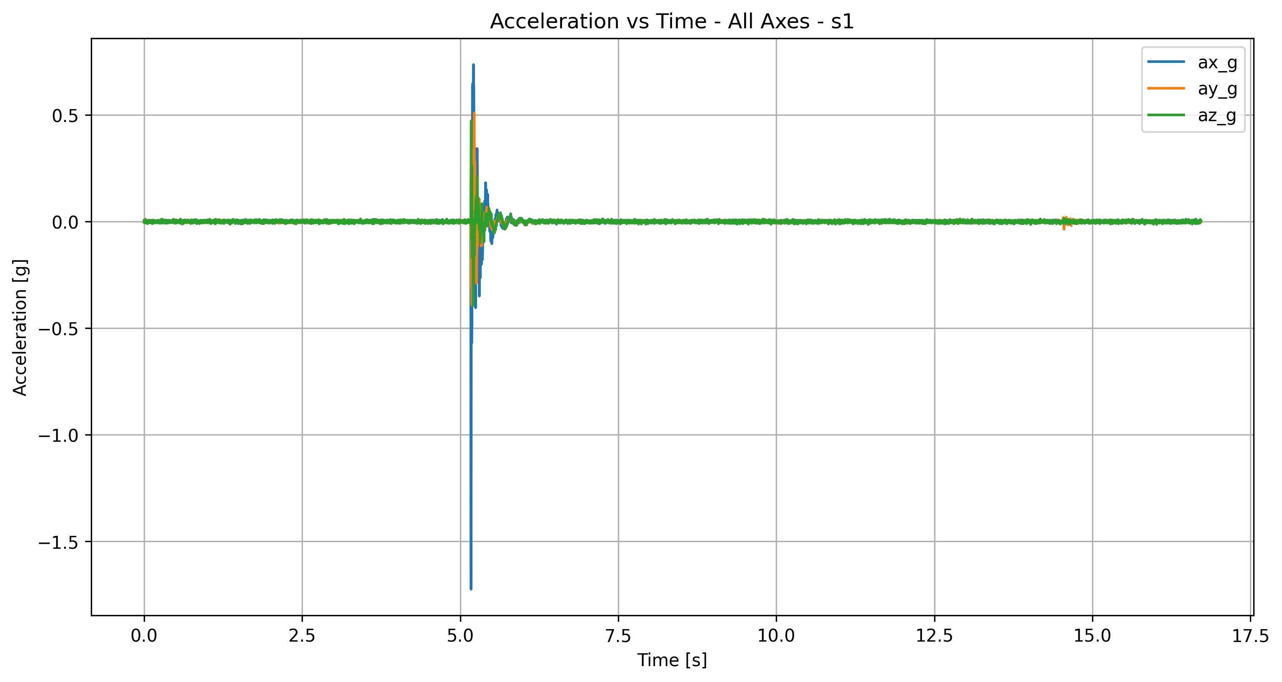
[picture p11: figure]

Figure 1: Acceleration vs Time for Sensor 1 mounted at the printer base.

Sensor 1 exhibited lower overall vibration amplitudes compared to the moving print head sensor. The base structure behaved relatively rigidly, with the dominant response occurring primarily in the X-axis direction.

### 4.2 Sensor 2 – Upper Frame

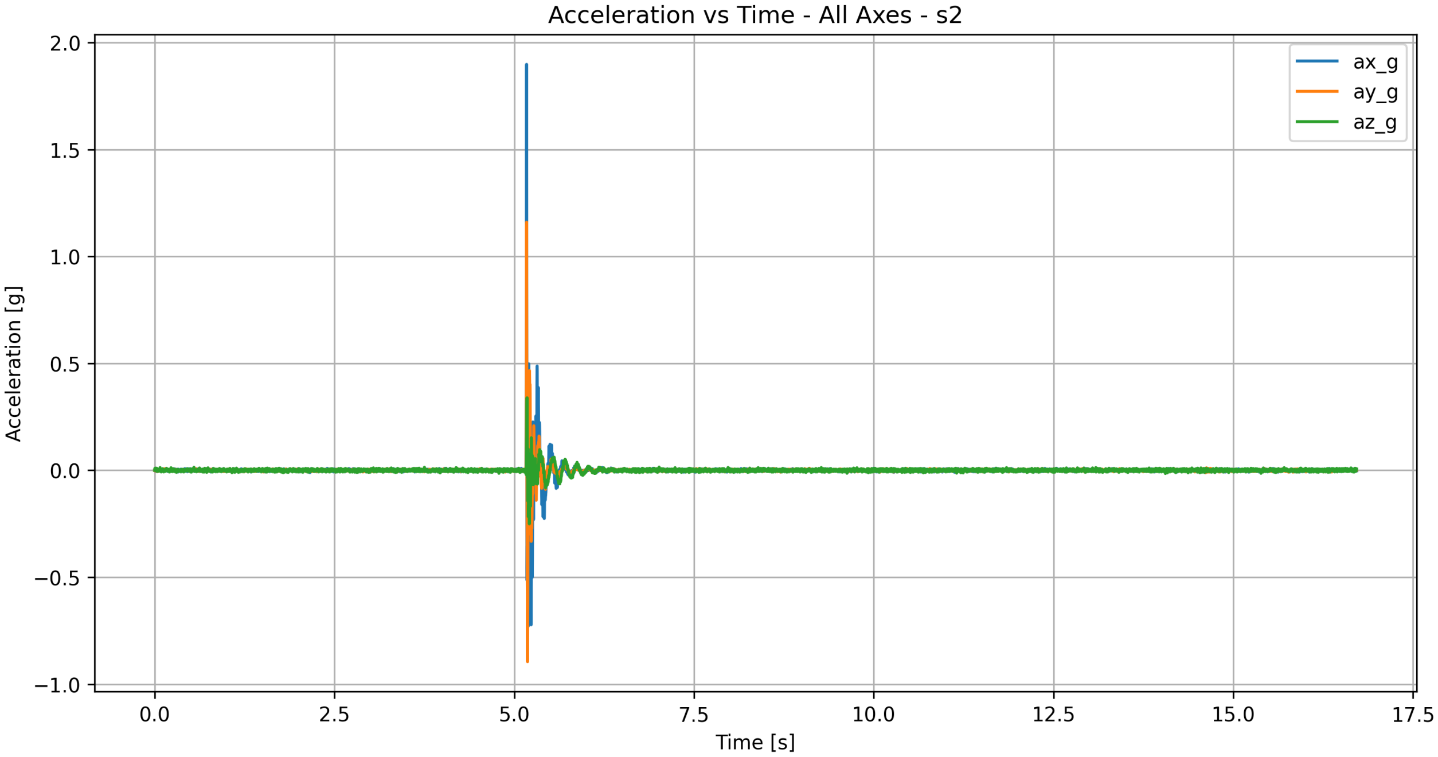
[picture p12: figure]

Figure 2: Acceleration vs Time for Sensor 2 mounted toward the upper section of the frame.

Sensor 2 showed increased vibration amplitudes compared to Sensor 1, indicating amplification of vibration as the distance from the base increased.

### 4.3 Sensor 3 – Print Head / Extruder

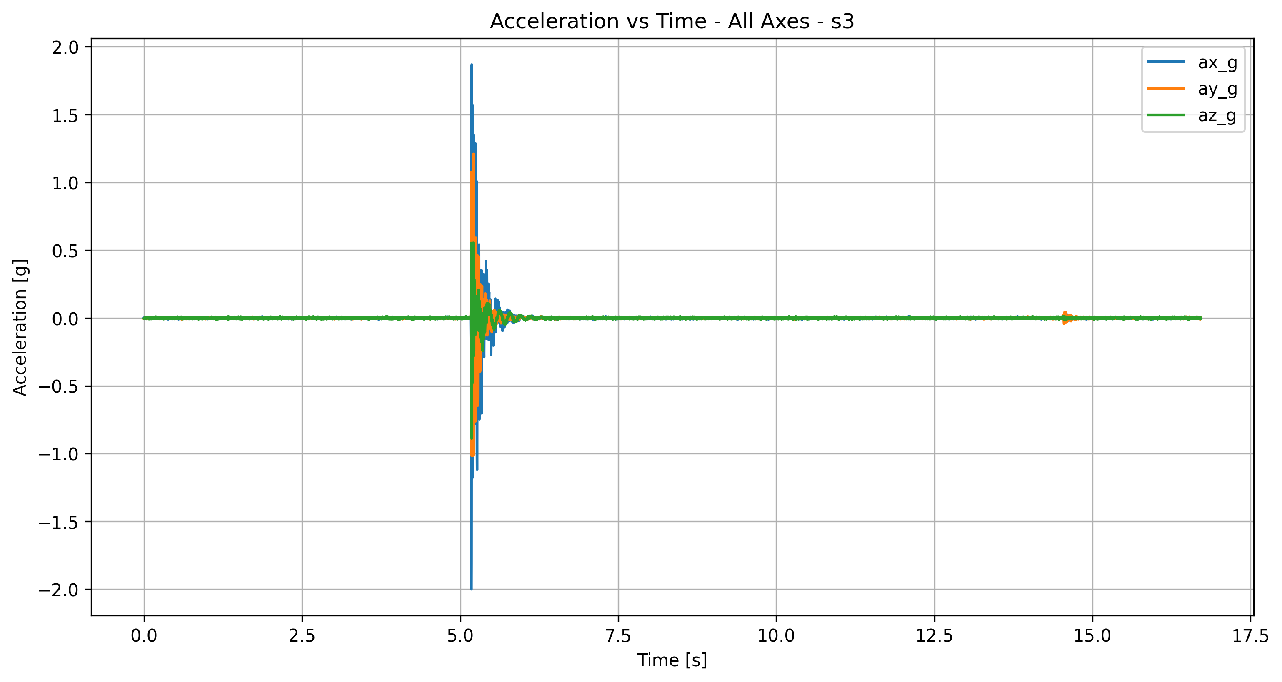
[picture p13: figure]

Figure 3: Acceleration vs Time for Sensor 3 mounted on the printer head/extruder assembly.

Sensor 3 produced the largest vibration amplitudes and the most energetic response overall. Since the extruder assembly is part of the moving mass of the printer, higher dynamic amplification was expected.
The print head location also exhibited a longer decay period after excitation, suggesting lower effective structural stiffness and increased dynamic compliance at that location.

## 5 Frequency Domain Analysis

Fast Fourier Transform (FFT) analysis was performed on the acceleration data to identify dominant vibration frequencies.
The FFT plots for each sensor are shown in Figures 4, 5, and 6.

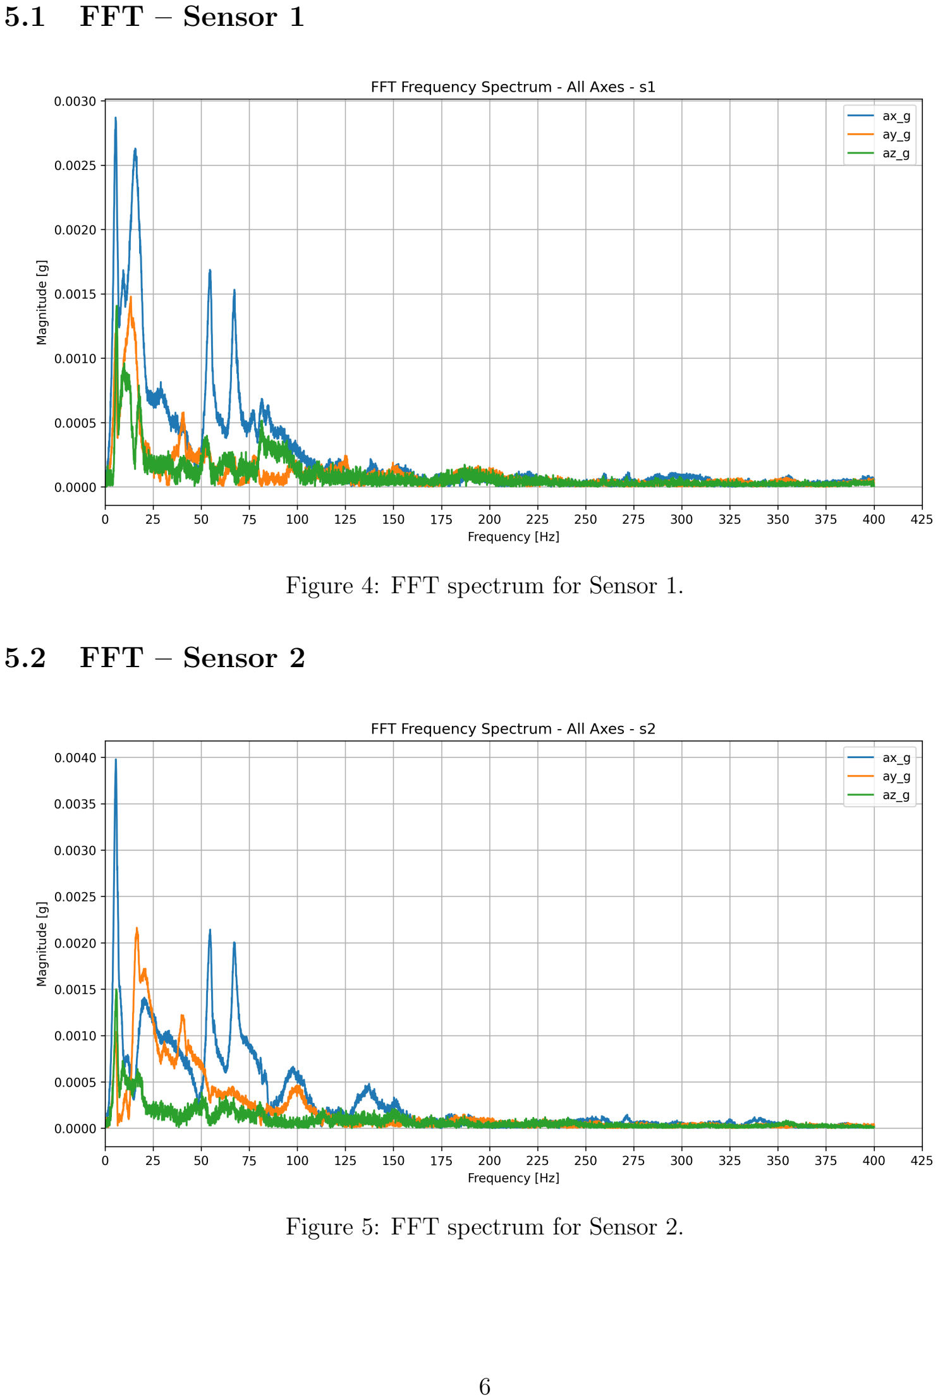
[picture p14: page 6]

### 5.1 FFT – Sensor 1

Figure 4: FFT spectrum for Sensor 1.

### 5.2 FFT – Sensor 2

Figure 5: FFT spectrum for Sensor 2.

### 5.3 FFT – Sensor 3

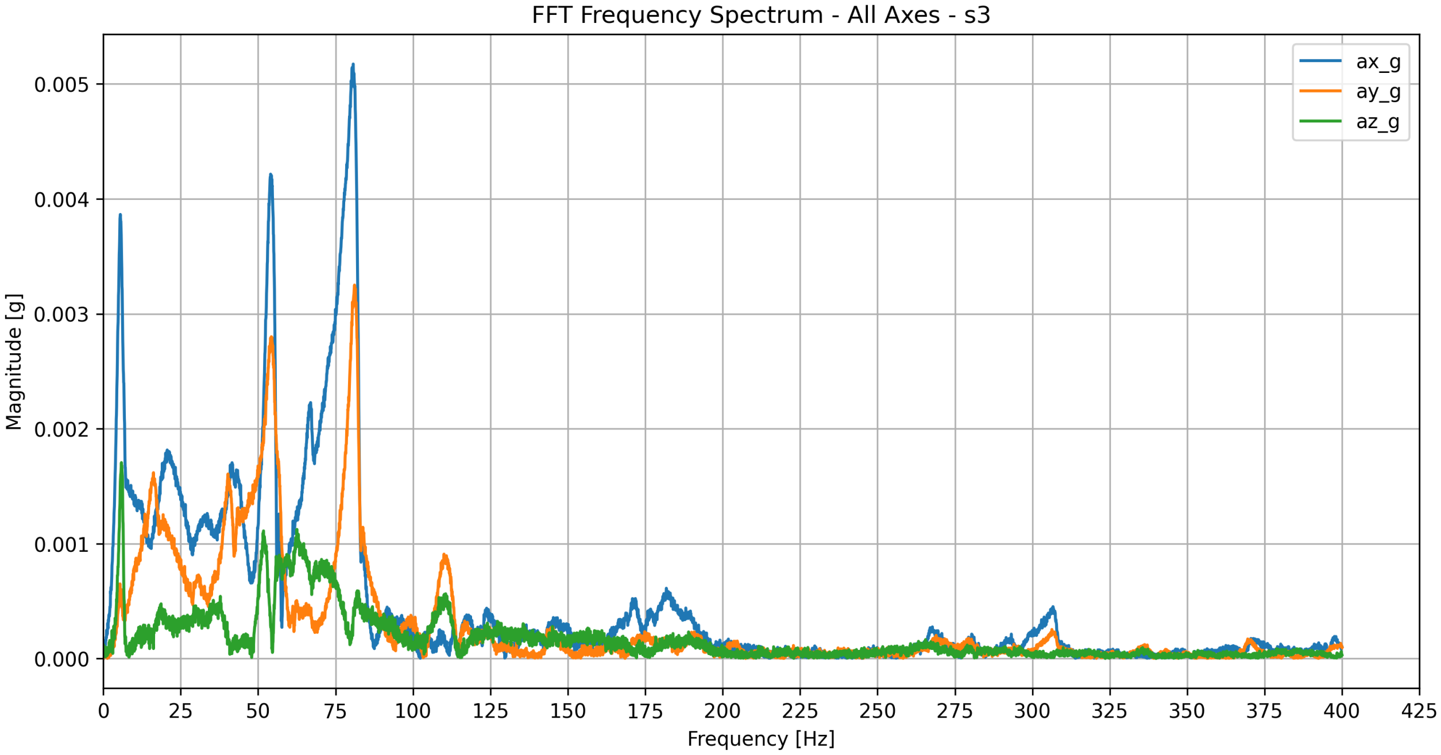
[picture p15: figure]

Figure 6: FFT spectrum for Sensor 3.

## 6 Overlapped FFT Comparison Between Sensors

To compare the structural response at each sensor location, overlapped FFT plots were generated for each axis.

### 6.1 X-Axis Comparison

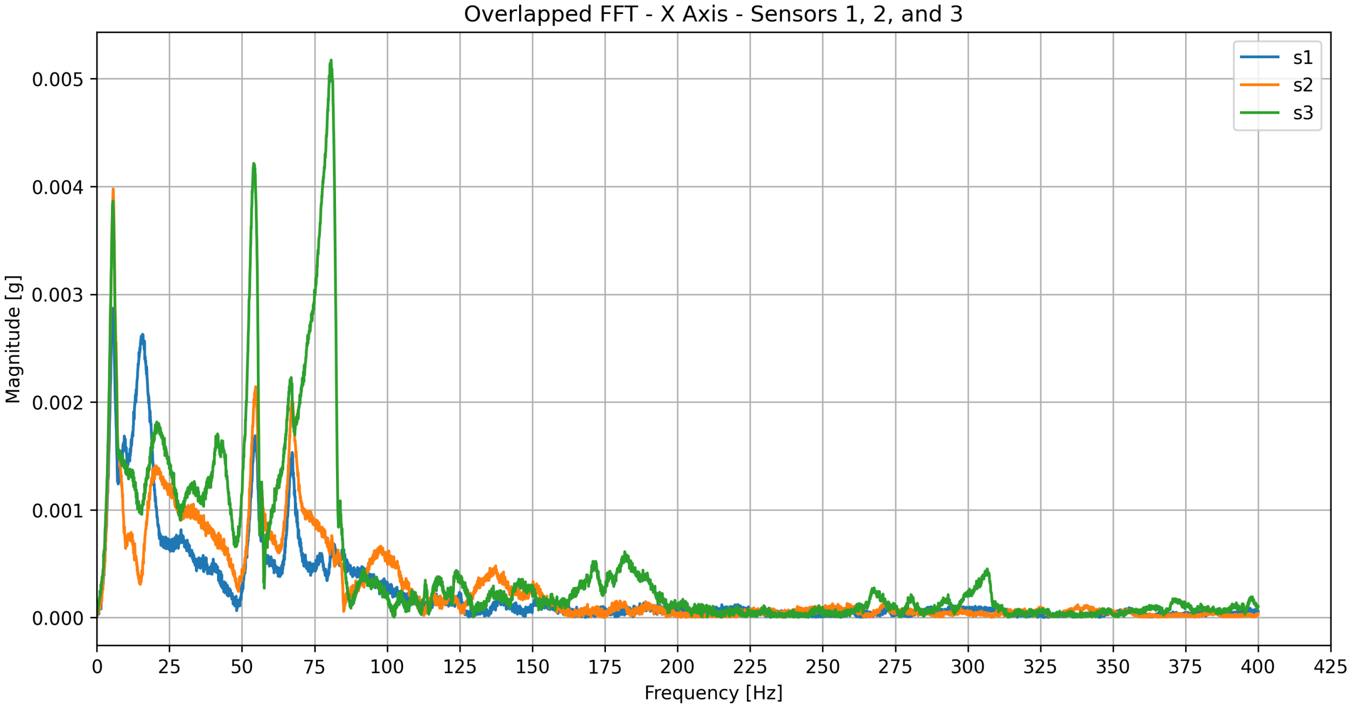
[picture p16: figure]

Figure 7: Overlapped FFT response for the X-axis across all sensors.

The X-axis exhibited the highest vibration amplitudes overall. Sensor 3 showed strong peaks near 80 Hz, which were significantly larger than the corresponding peaks observed at the frame-mounted sensors.

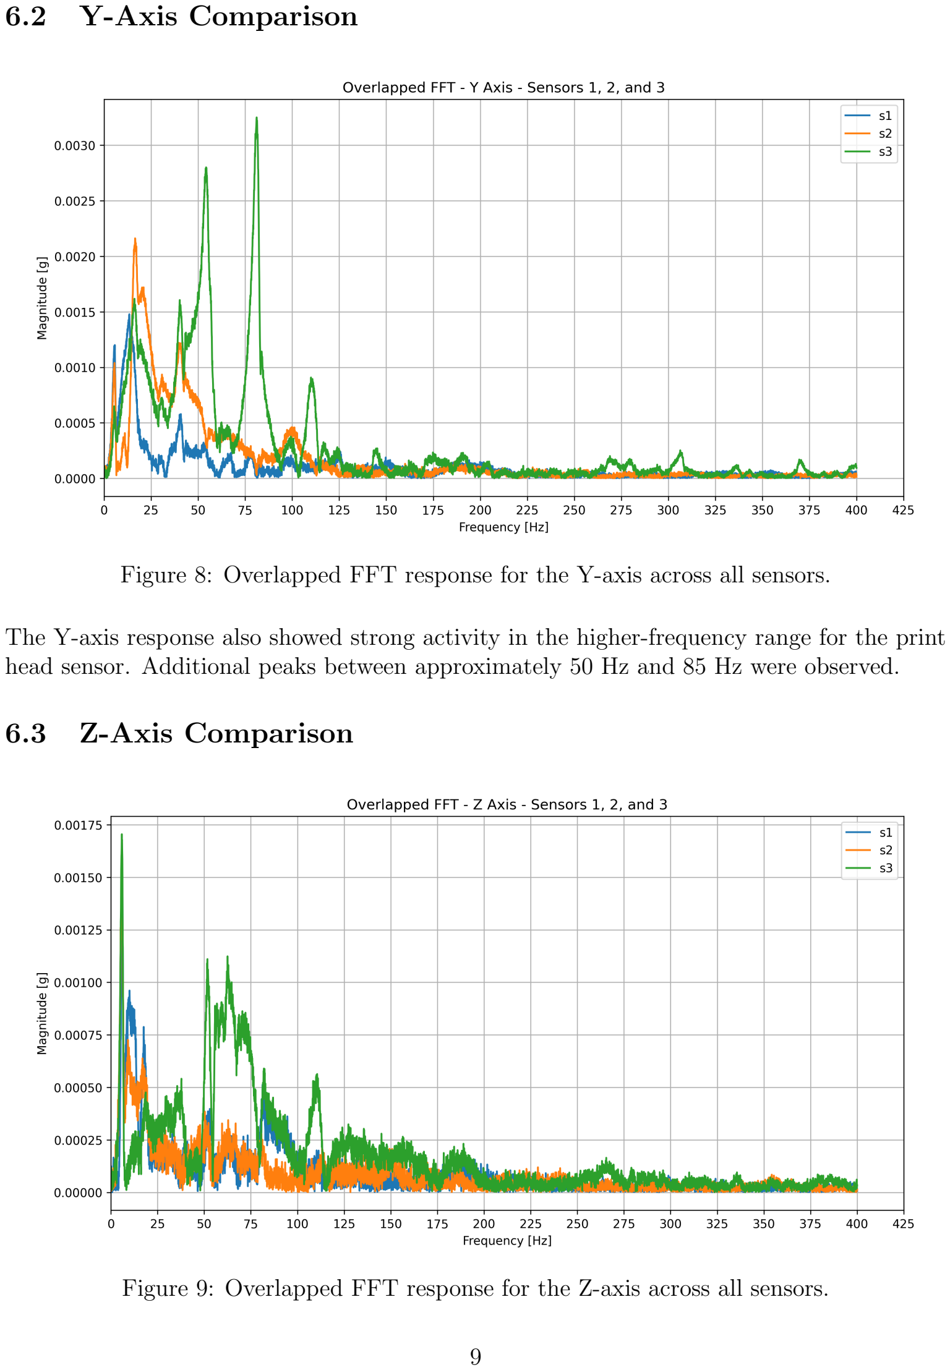
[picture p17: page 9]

### 6.2 Y-Axis Comparison

Figure 8: Overlapped FFT response for the Y-axis across all sensors.

The Y-axis response also showed strong activity in the higher-frequency range for the print head sensor. Additional peaks between approximately 50 Hz and 85 Hz were observed.

### 6.3 Z-Axis Comparison

Figure 9: Overlapped FFT response for the Z-axis across all sensors.

The Z-axis exhibited lower overall amplitudes compared to the X-axis and Y-axis. However, measurable structural vibration was still present throughout the tested frequency range.

## 7 Dominant Frequency Results

Table 2 summarizes the dominant frequencies detected for each sensor axis.

Table 2: Dominant Frequencies by Sensor Axis

Sensor Axis Dominant Frequency [Hz] Dominant Magnitude [g]

s1 ax | 5.50 | 0.002870
s1 ay | 13.46 | 0.001479
s1 az | 5.98 | 0.001407
s2 ax | 5.62 | 0.003978
s2 ay | 16.51 | 0.002162
s2 az | 5.80 | 0.001499
s3 ax | 80.71 | 0.005173
s3 ay | 81.12 | 0.003250
s3 az | 5.86 | 0.001705

## 8 Discussion

Several observations can be made from the current experimental results:

- The printer structure exhibits measurable vibration modes in multiple axes.
- The print head/extruder assembly experiences the largest vibration amplitudes, which is expected due to the moving mass and reduced structural rigidity compared to the base frame.
- Lower-frequency structural response near approximately 5–6 Hz was consistently observed across all sensors.
- Higher-frequency vibration components near 80 Hz were strongly present at the print head location, suggesting localized dynamic behavior associated with the moving assembly.
- The rigid sensor mounting method successfully allowed transmission of measurable structural vibration into the accelerometers.
- The use of multiple synchronized sensors provided useful information regarding vibration propagation through the printer structure.

## 9 Conclusions

The current experimental setup successfully demonstrated the capability of using low-cost MEMS accelerometers for multi-point structural vibration measurements.
The three-sensor configuration allowed identification of differences in vibration response between the printer base, upper frame, and print head assembly. The data indicates that the print head region experiences significantly greater dynamic excitation and contains higher-frequency vibration content compared to the frame-mounted sensors.
These results suggest that the experimental platform is capable of capturing meaningful vibration behavior and may be suitable for continued investigation into structural dynamics, resonance behavior, damping characteristics, and comparison between low-cost and higherend sensing systems.
Future work will focus on:
- Experimental modal analysis
- Improved excitation methods
- Validation against theoretical models
- Comparison with industrial-grade accelerometers
- Investigation of resonance behavior during active printing
- Structural stiffness and damping estimation

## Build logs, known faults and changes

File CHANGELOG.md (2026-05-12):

# Changelog

All notable changes and development progress for the Structural Vibration Analyzer project are documented here.

---

# [Initial Concept Phase]

## Project Planning
### Added
- Initial concept for a low-cost structural vibration analyzer
- Goal of developing an educational vibration-analysis platform
- Preliminary research into vibration-analysis methods and FFT processing
- Evaluation of low-cost MEMS accelerometers for vibration measurements

### Research
- Investigated industrial vibration-analysis systems
- Compared commercial accelerometers and vibration analyzers
- Studied vibration-analysis applications in industry
- Evaluated feasibility for educational laboratory implementation

---

# [Arduino Mega Development Phase]

## Initial Hardware Setup
### Added
- Arduino Mega 2560 initial acquisition platform
- Single MPU6050 accelerometer integration
- Basic acceleration acquisition over I2C
- Serial acceleration output to PC

### Implemented
- Time-domain acceleration measurements
- Initial FFT processing
- Basic graph visualization

### Tested
- Impact testing on structural systems
- Preliminary vibration measurements on mechanical structures

---

# [Higher Sampling Rate Development]

## Sampling Optimization
### Improved
- Increased sampling frequency on Arduino Mega
- Reduced serial bottlenecks
- Improved timing consistency

### Investigated
- Maximum achievable MPU6050 sampling rate
- Limitations of Arduino Mega serial communication
- Data-transfer bottlenecks during high-frequency acquisition

### Result
- Determined need for higher-performance microcontroller platform

---

# [ESP32 Migration Phase]

## ESP32 Integration
### Added
- ESP32-based acquisition system
- Improved processing capability
- Higher-speed serial communication
- Support for higher sampling frequencies

### Improved
- Sampling stability
- Real-time acquisition performance
- Data throughput capabilities

### Fixed
- Serial communication timing issues
- Logger synchronization problems

---

# [Multi-Sensor Expansion]

## Three-Sensor System
### Added
- Support for three MPU6050 accelerometers
- PCA9548A I2C multiplexer integration
- Simultaneous multi-sensor acquisition

### Implemented
- Sensor channel switching
- Independent sensor reading system
- Multi-location structural vibration measurements

### Sensor Locations
- S1 mounted at printer base/frame
- S2 mounted at upper frame structure
- S3 mounted at print head/extruder assembly

---

# [Binary Communication Implementation]

## Data Transmission Optimization
### Added
- Binary serial data transmission
- Compact packet structure
- Faster PC-side data reception

### Improved
- Higher effective sampling rates
- Reduced serial overhead
- More stable high-frequency acquisition

### Result
- Stable operation achieved near 400–800 Hz sampling rates

---

# [Python Logger Development]

## Logging System
### Added
- Python-based serial logger
- Automatic file creation
- Timestamped recordings
- Structured raw-data storage

### Improved
- User interaction during acquisition
- Dataset management workflow
- File organization system

### Fixed
- Logger startup synchronization
- Serial buffer issues
- Data corruption during long recordings

---

# [FFT Analyzer Development]

## Signal Processing Expansion
### Added
- FFT processing for X, Y, and Z axes independently
- Resultant acceleration analysis
- Automatic FFT graph generation
- Processed data export system

### Implemented
- Frequency-domain visualization
- Axis-by-axis vibration analysis
- Comparative FFT analysis between sensors

### Added Graph Features
- Frequency tick marks
- Adjustable grid spacing
- Automatic graph saving
- Organized processed-data folders

---

# [Experimental Testing Phase]

## Structural Vibration Experiments
### Tested
- Impact-response measurements
- Operational vibration analysis
- Multi-location structural response

### Observed
- Dominant low-frequency structural behavior
- Vibration transmission differences across printer structure
- Higher vibration amplitudes near moving print head assembly

### Preliminary Findings
- Estimated structural resonance behavior near approximately 6 Hz
- Increased excitation magnitude improved frequency visibility
- Rigid sensor mounting significantly improved data quality

---

### Research Goals
- Evaluate limitations of low-cost sensors
- Determine educational usefulness
- Develop accessible vibration-analysis tools for students

---

# [Current State]

## Current Capabilities
### System Features
- ESP32-based acquisition
- Three simultaneous accelerometers
- PCA9548A multiplexer support
- Binary serial communication
- High-rate sampling
- Python logger and analyzer
- FFT analysis for all axes
- Multi-sensor FFT overlays
- Automatic graph export system

### Experimental Platform
- Elegoo Centauri Carbon 3D printer
- Rigid multi-sensor mounting system
- Operational and impact testing capability

### Current Focus
- Improving measurement quality
- Increasing acquisition performance
- Developing educational vibration-analysis workflow
- Expanding experimental validation

---

# [Planned Future Development]

## Future Work
### Planned
- SD card standalone logging
- Wireless monitoring system
- Real-time web dashboard
- Higher-end accelerometer integration
- ADXL355 implementation
- Teensy 4.1 or STM32 migration
- Modal analysis tools
- Natural frequency estimation automation
- Industrial sensor comparison studies
- Calibration and validation procedures

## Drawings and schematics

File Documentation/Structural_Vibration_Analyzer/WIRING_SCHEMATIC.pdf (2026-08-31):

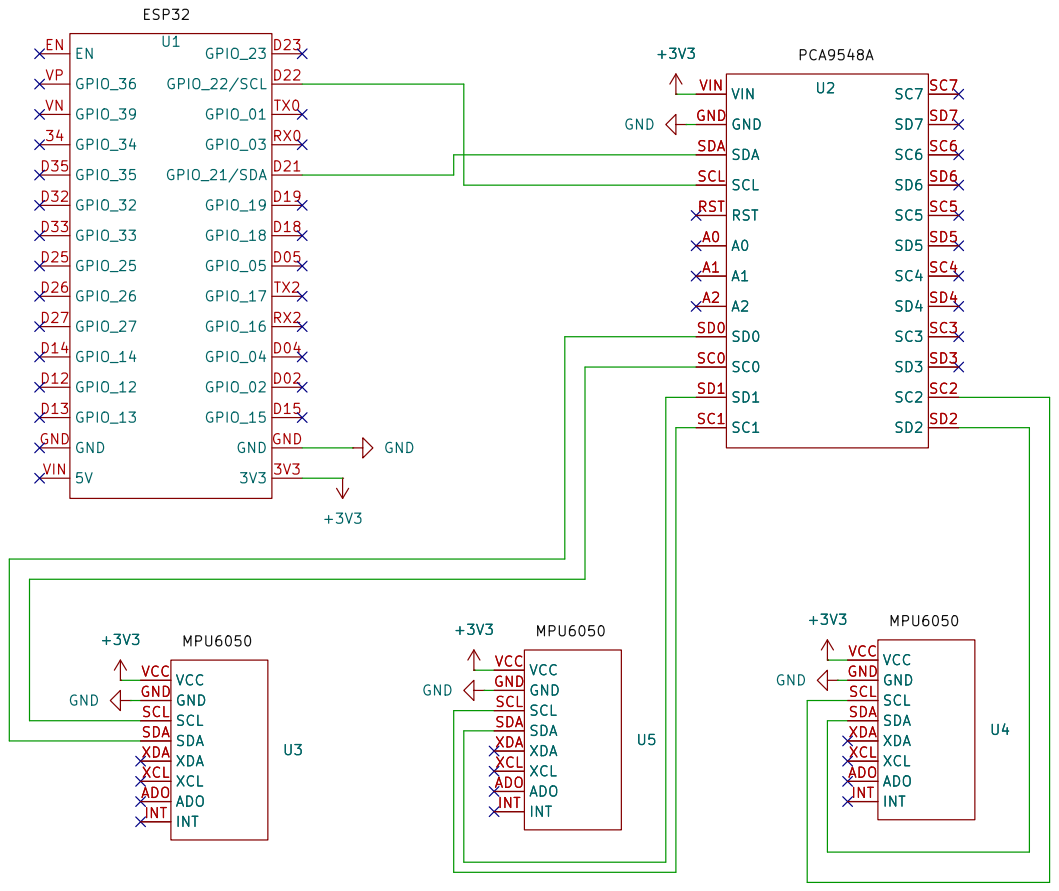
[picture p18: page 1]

ESP32 Multi-Sensor Vibration Acquisition System

Sheet: /
File: Structural_Vibration_Analyzer.kicad_sch
Title: Structural Vibration Analyzer

Size: A4 | Rev: A
KiCad E.D.A. 10.0.5 | Id: 1/1

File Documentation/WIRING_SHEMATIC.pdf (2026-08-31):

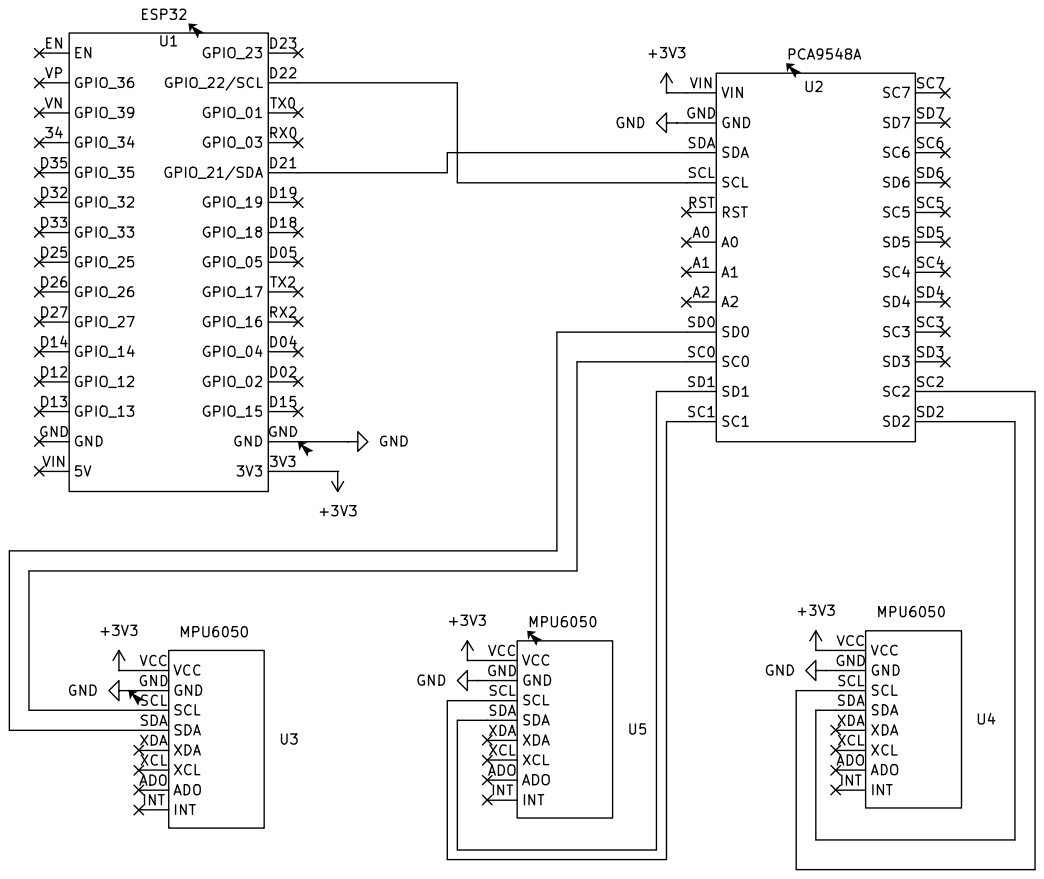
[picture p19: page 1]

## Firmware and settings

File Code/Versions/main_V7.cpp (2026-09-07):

// V7 - Dual-mode (FAST_ACCEL / FULL_DIAGNOSTIC) auto-detected MPU6050
// binary vibration logger with I2C health monitoring.
// Structural Vibration Analyzer

#include <Arduino.h>
#include <Wire.h>

// ============================================================
// ESP32 + PCA9548A + AUTO-DETECTED MPU6050 BINARY LOGGER
// ============================================================
//
// Validated acquisition configuration (see Data/validation run history):
//   I2C clock:                 400 kHz
//   Nominal ESP32 poll rate:   see SAMPLE_RATE_HZ below (currently 800 Hz)
//   MPU6050 DLPF_CFG:          1 (~184 Hz accel BW, ~188 Hz gyro BW)
//   MPU6050 SMPLRT_DIV:        0
//   MPU6050 internal register-update rate: computed below from DLPF_CFG/
//                              SMPLRT_DIV, not hardcoded (see
//                              MPU_INTERNAL_RATE_HZ).
//   Accelerometer:             +/-8 g
//   Gyroscope:                 +/-250 deg/s (FULL_DIAGNOSTIC mode only)
//   Serial:                    921600 baud
//
// This firmware supports two acquisition modes, selected by the
// ACQUISITION_MODE constant below (change and reflash to switch - a
// runtime-switchable mode would require adding a serial command
// protocol, which is not justified for how infrequently this changes):
//
//   ACQ_MODE_FAST_ACCEL (default) - accelerometer-only 6-byte reads per
//     sensor. This is the normal mode for vibration/FFT analysis. Gyro
//     calibration is skipped entirely in this mode (no gyro data is
//     acquired, so there is nothing to calibrate), which also removes
//     the ~2 second calibration delay at startup.
//
//   ACQ_MODE_FULL_DIAGNOSTIC - full 14-byte accel+temperature+gyro
//     reads per sensor (temperature is read but not transmitted, as
//     before). Gyro zero-rate bias is calibrated at startup as before.
//     Use this mode when gyro data is specifically needed (e.g.
//     investigating torsional modes or checking mounting integrity) -
//     analyze_fft.py's FFT/FRF pipeline does not currently use gyro
//     data, so FAST_ACCEL is the default for routine work.
//
// The PCA9548A channels 0, 1, and 2 are scanned at startup. Only
// detected MPU6050 sensors are configured and streamed - the firmware
// does not assume any particular sensor count; it works with however
// many are actually present (currently 2 in the fielded hardware, but
// nothing here is hardcoded to that number).
//
// IMPORTANT:
// - Accelerometer samples are NOT gravity-zeroed in firmware.
//   Static/DC removal is performed later in the PC analysis.
// - In FULL_DIAGNOSTIC mode, gyroscope zero-rate bias is estimated
//   while stationary and removed.
// - A binary configuration packet identifies the active acquisition
//   configuration and PCA channels.
// - Data packet payload size varies with both the number of detected
//   sensors AND the acquisition mode.
// - I2C error counters (NACK vs. timeout/short-read) are cumulative,
//   not per-sample, to avoid adding meaningful per-frame overhead -
//   they still let acquisition-health issues be diagnosed after a run.
//
// Binary frame:
//   sync0, sync1, packet_type, payload_size, payload..., checksum
//
// CONFIG payload:
//   firmware_version     [u8]   bump when protocol/config changes
//   dlpf_cfg              [u8]
//   smplrt_div             [u8]
//   acquisition_mode      [u8]   0 = FAST_ACCEL, 1 = FULL_DIAGNOSTIC
//   target_poll_rate_hz   [u32]
//   sensor_count          [u8]
//   active PCA channels   [u8 x sensor_count]
//
// DATA payload:
//   t_us                    [u32]
//   sample_index            [u32]
//   missed_deadlines_total  [u32]  cumulative, all-time
//   i2c_error_total         [u32]  cumulative: ANY I2C problem (bad
//                                  endTransmission status on any write,
//                                  OR a short/failed requestFrom read)
//   i2c_nack_total          [u32]  cumulative subset: NACK on address
//                                  or data - suggests a genuine bus/
//                                  wiring problem
//   i2c_timeout_total       [u32]  cumulative subset: timeout or short
//                                  read - more consistent with timing
//                                  overload than a hard wiring fault,
//                                  though this classification is an
//                                  engineering judgement call, not a
//                                  certainty
//   for each active sensor, in CONFIG order:
//     FAST_ACCEL mode:      ax ay az [int16 each]                (6 bytes)
//     FULL_DIAGNOSTIC mode: ax ay az gx gy gz [int16 each]       (12 bytes)
//
// Per-cycle timing diagnostics (cycle duration, scheduling lateness)
// and per-transaction I2C sub-timing are intentionally NOT transmitted
// here - they were used during acquisition-characterization validation
// (see main_validation.cpp), but the achieved sampling rate and jitter
// are fully derivable PC-side from consecutive t_us values (confirmed
// to agree with device-measured cycle duration to within ~1 us during
// validation), so transmitting them again in every production frame
// would be redundant per-sample overhead with no analytical benefit.
//
// All multibyte numeric fields are little-endian.
// ============================================================

// ============================================================
// ACQUISITION MODE - change this constant and reflash to switch modes.
// ============================================================
const uint8_t ACQ_MODE_FAST_ACCEL = 0;
const uint8_t ACQ_MODE_FULL_DIAGNOSTIC = 1;
const uint8_t ACQUISITION_MODE = ACQ_MODE_FAST_ACCEL;

// Firmware/protocol version. Bump any time DLPF_CFG, SMPLRT_DIV, the
// frame layout, or the acquisition-mode set changes, so a recorded
// dataset's .meta.json sidecar can always be traced back to the exact
// firmware that produced it.
const uint8_t FIRMWARE_VERSION = 7;

#define MPU_ADDR 0x68
#define PCA_ADDR 0x70

#define SDA_PIN 21
#define SCL_PIN 22

const uint32_t SERIAL_BAUD = 921600;

const uint32_t I2C_CLOCK_HZ = 400000;

// ESP32 output stream target. Validated for 2-3 sensors in FAST_ACCEL
// mode at 400 kHz I2C; if the sensor count or acquisition mode changes
// meaningfully, this should be re-validated with main_validation.cpp
// rather than assumed.
//
// 1,000,000 / SAMPLE_RATE_HZ is not necessarily an integer, so a
// rational microsecond scheduler is used below instead of truncating
// the period - this is generic to whatever SAMPLE_RATE_HZ is set to.
const uint32_t SAMPLE_RATE_HZ = 800;
const uint32_t SAMPLE_PERIOD_BASE_US = 1000000UL / SAMPLE_RATE_HZ;
const uint32_t SAMPLE_PERIOD_REMAINDER = 1000000UL % SAMPLE_RATE_HZ;

// MPU6050 register configuration.
const uint8_t DLPF_CFG = 0x01;       // ~184 Hz accel BW, ~188 Hz gyro BW
const uint8_t GYRO_CONFIG = 0x00;    // +/-250 deg/s
const uint8_t ACCEL_CONFIG = 0x10;   // +/-8 g
const uint8_t SMPLRT_DIV = 0x00;

// MPU6050 internal register-update rate, CALCULATED from the active
// DLPF_CFG/SMPLRT_DIV rather than hardcoded. This formula
// (gyro output rate / (1+SMPLRT_DIV)) is valid for DLPF_CFG 1-6, which
// is what this project always uses (DLPF_CFG=1 above); the 8 kHz base
// rate case (DLPF_CFG=0 or 7) is not handled here since it is not used.
const uint32_t MPU_GYRO_OUTPUT_RATE_HZ = 1000;
const uint32_t MPU_INTERNAL_RATE_HZ =
    MPU_GYRO_OUTPUT_RATE_HZ / (1 + SMPLRT_DIV);
const uint32_t MPU_INTERNAL_PERIOD_US = 1000000UL / MPU_INTERNAL_RATE_HZ;

// Computed, not hardcoded - the acquisition Nyquist frequency implied by
// the current SAMPLE_RATE_HZ. Printed at startup; also useful if this
// project ever wants to sanity-check the analysis-side Nyquist against
// the firmware's own target.
const float ESP32_OUTPUT_NYQUIST_HZ = SAMPLE_RATE_HZ / 2.0f;

// Maximum number of sensors/channels used by this project. The system
// does NOT assume this many sensors are actually present - detection is
// dynamic (see detectSensors()). This is only an upper bound on the
// number of PCA9548A channels scanned.
const int MAX_SENSORS = 3;
const uint8_t POSSIBLE_SENSOR_CHANNELS[MAX_SENSORS] = {0, 1, 2};

// Gyro zero-rate calibration samples (FULL_DIAGNOSTIC mode only).
// 500 samples at the MPU's actual internal rate (computed above, not
// hardcoded) covers roughly half a second at 1000 Hz; adjust if a
// longer calibration window is wanted.
const int CALIBRATION_SAMPLES = 500;

const float ACCEL_SCALE = 4096.0f;   // +/-8 g raw counts per g
const float GYRO_SCALE = 131.0f;     // +/-250 deg/s raw counts per deg/s

const uint8_t SYNC0 = 0xAA;
const uint8_t SYNC1 = 0x55;

const uint8_t PACKET_TYPE_DATA = 0x01;
const uint8_t PACKET_TYPE_CONFIG = 0x02;

const uint8_t BYTES_PER_SENSOR_FAST_ACCEL = 3 * 2;        // ax, ay, az
const uint8_t BYTES_PER_SENSOR_FULL_DIAGNOSTIC = 6 * 2;    // + gx, gy, gz
const uint8_t BYTES_PER_SENSOR =
    (ACQUISITION_MODE == ACQ_MODE_FULL_DIAGNOSTIC)
        ? BYTES_PER_SENSOR_FULL_DIAGNOSTIC
        : BYTES_PER_SENSOR_FAST_ACCEL;

// t_us + sample_index + missed_deadlines_total + i2c_error_total +
// i2c_nack_total + i2c_timeout_total
const uint8_t BASE_DATA_PAYLOAD_SIZE = 4 * 6;

const uint8_t MAX_PAYLOAD_SIZE = 64;

struct GyroOffset {
  float gx = 0.0f;
  float gy = 0.0f;
  float gz = 0.0f;
};

uint32_t streamStartUs = 0;
uint32_t sampleIndex = 0;
uint32_t missedDeadlines = 0;

// Cumulative I2C health counters. Reset to zero right before streaming
// starts (see setup()) so detection/setup-time I2C activity doesn't
// contaminate the run's reported error statistics.
uint32_t i2cErrorTotal = 0;
uint32_t i2cNackTotal = 0;
uint32_t i2cTimeoutTotal = 0;

GyroOffset gyroOffsets[MAX_SENSORS];
uint8_t activeChannels[MAX_SENSORS];
uint8_t activeSensorCount = 0;
uint8_t dataPayloadSize = BASE_DATA_PAYLOAD_SIZE;

// ============================================================
// I2C ERROR CLASSIFICATION
// ============================================================

// Wire.endTransmission() status codes (standard Arduino Wire semantics):
//   0 = success, 1 = data too long, 2 = NACK on address,
//   3 = NACK on data, 4 = other error, 5 = timeout (ESP32 core).
void recordI2cWriteStatus(uint8_t status) {
  if (status == 0) {
    return;
  }

  i2cErrorTotal++;

  if (status == 2 || status == 3) {
    i2cNackTotal++;
  } else if (status == 5) {
    i2cTimeoutTotal++;
  }
  // status 1 and 4 fold into i2cErrorTotal only - neither a clear
  // NACK-like bus fault nor clearly a timing symptom.
}

// A short read is treated as an I2C error, bucketed under the
// "timing-suggestive" counter as an engineering judgement call (short
// reads most commonly arise from bus contention under load), not a
// certainty - it could also stem from a transient electrical glitch.
void recordI2cReadResult(int expectedBytes, int actualBytes) {
  if (actualBytes == expectedBytes) {
    return;
  }

  i2cErrorTotal++;
  i2cTimeoutTotal++;
}

// ============================================================
// I2C / MPU HELPERS
// ============================================================

void selectPCAChannel(uint8_t channel) {
  if (channel > 7) return;

  Wire.beginTransmission(PCA_ADDR);
  Wire.write(1U << channel);
  const uint8_t status = Wire.endTransmission(true);
  recordI2cWriteStatus(status);
}

void disablePCAChannels() {
  Wire.beginTransmission(PCA_ADDR);
  Wire.write(0x00);
  Wire.endTransmission(true);
}

bool writeMPU(uint8_t reg, uint8_t value) {
  Wire.beginTransmission(MPU_ADDR);
  Wire.write(reg);
  Wire.write(value);
  const uint8_t status = Wire.endTransmission(true);
  recordI2cWriteStatus(status);
  return status == 0;
}

// Full 14-byte accel+temperature+gyro burst read. Used only in
// ACQ_MODE_FULL_DIAGNOSTIC.
bool readMPU(
    int16_t &ax, int16_t &ay, int16_t &az,
    int16_t &gx, int16_t &gy, int16_t &gz) {

  Wire.beginTransmission(MPU_ADDR);
  Wire.write(0x3B);

  const uint8_t writeStatus = Wire.endTransmission(false);
  recordI2cWriteStatus(writeStatus);
  if (writeStatus != 0) {
    return false;
  }

  const int bytesRead = Wire.requestFrom((int)MPU_ADDR, 14, (int)true);
  recordI2cReadResult(14, bytesRead);

  if (bytesRead != 14) {
    return false;
  }

  ax = (int16_t)((Wire.read() << 8) | Wire.read());
  ay = (int16_t)((Wire.read() << 8) | Wire.read());
  az = (int16_t)((Wire.read() << 8) | Wire.read());

  Wire.read();
  Wire.read();  // temperature ignored

  gx = (int16_t)((Wire.read() << 8) | Wire.read());
  gy = (int16_t)((Wire.read() << 8) | Wire.read());
  gz = (int16_t)((Wire.read() << 8) | Wire.read());

  return true;
}

// Accelerometer-only 6-byte burst read (registers 0x3B-0x40, confirmed
// contiguous in the MPU6050 register map). Used only in
// ACQ_MODE_FAST_ACCEL - this is the normal mode for vibration analysis.
bool readAccelOnly(int16_t &ax, int16_t &ay, int16_t &az) {
  Wire.beginTransmission(MPU_ADDR);
  Wire.write(0x3B);

  const uint8_t writeStatus = Wire.endTransmission(false);
  recordI2cWriteStatus(writeStatus);
  if (writeStatus != 0) {
    return false;
  }

  const int bytesRead = Wire.requestFrom((int)MPU_ADDR, 6, (int)true);
  recordI2cReadResult(6, bytesRead);

  if (bytesRead != 6) {
    return false;
  }

  ax = (int16_t)((Wire.read() << 8) | Wire.read());
  ay = (int16_t)((Wire.read() << 8) | Wire.read());
  az = (int16_t)((Wire.read() << 8) | Wire.read());

  return true;
}

bool mpuPresentOnSelectedChannel() {
  Wire.beginTransmission(MPU_ADDR);
  return Wire.endTransmission(true) == 0;
}

bool setupMPUOnSelectedChannel() {
  bool ok = true;

  ok &= writeMPU(0x6B, 0x00);          // wake up
  delay(100);

  ok &= writeMPU(0x1A, DLPF_CFG);
  ok &= writeMPU(0x1B, GYRO_CONFIG);
  ok &= writeMPU(0x1C, ACCEL_CONFIG);
  ok &= writeMPU(0x19, SMPLRT_DIV);

  return ok;
}

// ============================================================
// PACKET HELPERS
// ============================================================

int16_t clampToInt16(float value) {
  if (value > 32767.0f) return 32767;
  if (value < -32768.0f) return -32768;
  return (int16_t)lround(value);
}

void appendU8(uint8_t *buffer, uint8_t &index, uint8_t value) {
  buffer[index++] = value;
}

void appendU32(uint8_t *buffer, uint8_t &index, uint32_t value) {
  buffer[index++] = (uint8_t)(value & 0xFF);
  buffer[index++] = (uint8_t)((value >> 8) & 0xFF);
  buffer[index++] = (uint8_t)((value >> 16) & 0xFF);
  buffer[index++] = (uint8_t)((value >> 24) & 0xFF);
}

void appendI16(uint8_t *buffer, uint8_t &index, int16_t value) {
  buffer[index++] = (uint8_t)(value & 0xFF);
  buffer[index++] = (uint8_t)((value >> 8) & 0xFF);
}

uint8_t calculateChecksum(const uint8_t *buffer, uint8_t length) {
  uint8_t checksum = 0;

  for (uint8_t i = 0; i < length; i++) {
    checksum ^= buffer[i];
  }

  return checksum;
}

void sendFrame(uint8_t packetType, const uint8_t *payload, uint8_t payloadSize) {
  const uint8_t frameSize = 2 + 1 + 1 + payloadSize + 1;
  uint8_t frame[2 + 1 + 1 + MAX_PAYLOAD_SIZE + 1];
  uint8_t idx = 0;

  appendU8(frame, idx, SYNC0);
  appendU8(frame, idx, SYNC1);
  appendU8(frame, idx, packetType);
  appendU8(frame, idx, payloadSize);

  for (uint8_t i = 0; i < payloadSize; i++) {
    appendU8(frame, idx, payload[i]);
  }

  frame[idx++] = calculateChecksum(frame, idx);
  Serial.write(frame, frameSize);
}

// ============================================================
// SENSOR DETECTION / CALIBRATION
// ============================================================

void detectSensors() {
  activeSensorCount = 0;

  Serial.println("# Scanning PCA9548A channels for MPU6050 sensors...");

  for (int i = 0; i < MAX_SENSORS; i++) {
    const uint8_t channel = POSSIBLE_SENSOR_CHANNELS[i];

    selectPCAChannel(channel);
    delay(5);

    Serial.print("# Checking PCA channel ");
    Serial.print(channel);
    Serial.print(": ");

    if (mpuPresentOnSelectedChannel()) {
      if (setupMPUOnSelectedChannel()) {
        Serial.println("MPU6050 found and configured");
        activeChannels[activeSensorCount++] = channel;
      } else {
        Serial.println("MPU6050 found but configuration failed");
      }
    } else {
      Serial.println("NOT FOUND");
    }
  }

  dataPayloadSize =
      BASE_DATA_PAYLOAD_SIZE + (activeSensorCount * BYTES_PER_SENSOR);

  Serial.print("# Detected sensor count: ");
  Serial.println(activeSensorCount);

  Serial.print("# Active PCA channels: ");
  if (activeSensorCount == 0) {
    Serial.println("none");
  } else {
    for (int i = 0; i < activeSensorCount; i++) {
      Serial.print(activeChannels[i]);
      if (i < activeSensorCount - 1) {
        Serial.print(", ");
      }
    }
    Serial.println();
  }

  Serial.print("# Binary data payload size: ");
  Serial.println(dataPayloadSize);
}

void calibrateGyros() {
  Serial.print("# Calibrating gyro zero-rate bias for ");
  Serial.print(activeSensorCount);
  Serial.println(" MPU6050 sensor(s). Keep all sensors still.");

  for (int sensor = 0; sensor < activeSensorCount; sensor++) {
    selectPCAChannel(activeChannels[sensor]);

    int64_t gxSum = 0;
    int64_t gySum = 0;
    int64_t gzSum = 0;
    int validSamples = 0;

    int16_t ax, ay, az, gx, gy, gz;

    for (int i = 0; i < CALIBRATION_SAMPLES; i++) {
      if (readMPU(ax, ay, az, gx, gy, gz)) {
        gxSum += gx;
        gySum += gy;
        gzSum += gz;
        validSamples++;
      }

      delayMicroseconds(MPU_INTERNAL_PERIOD_US);
    }

    if (validSamples == 0) {
      Serial.print("# WARNING: No valid gyro calibration samples for PCA channel ");
      Serial.println(activeChannels[sensor]);
      continue;
    }

    gyroOffsets[sensor].gx = gxSum / (float)validSamples;
    gyroOffsets[sensor].gy = gySum / (float)validSamples;
    gyroOffsets[sensor].gz = gzSum / (float)validSamples;

    Serial.print("# PCA channel ");
    Serial.print(activeChannels[sensor]);
    Serial.println(" gyro calibration complete.");
  }

  Serial.println("# Gyro calibration complete.");
}

// ============================================================
// CONFIG + DATA STREAM
// ============================================================

void sendConfigurationFrame() {
  uint8_t payload[1 + 1 + 1 + 1 + 4 + 1 + MAX_SENSORS];
  uint8_t idx = 0;

  appendU8(payload, idx, FIRMWARE_VERSION);
  appendU8(payload, idx, DLPF_CFG);
  appendU8(payload, idx, SMPLRT_DIV);
  appendU8(payload, idx, ACQUISITION_MODE);
  appendU32(payload, idx, SAMPLE_RATE_HZ);

  appendU8(payload, idx, activeSensorCount);
  for (int i = 0; i < activeSensorCount; i++) {
    appendU8(payload, idx, activeChannels[i]);
  }

  sendFrame(PACKET_TYPE_CONFIG, payload, idx);
}

void sendDataFrame() {
  uint8_t payload[MAX_PAYLOAD_SIZE];
  uint8_t idx = 0;

  appendU32(payload, idx, micros() - streamStartUs);
  appendU32(payload, idx, sampleIndex++);
  appendU32(payload, idx, missedDeadlines);
  appendU32(payload, idx, i2cErrorTotal);
  appendU32(payload, idx, i2cNackTotal);
  appendU32(payload, idx, i2cTimeoutTotal);

  for (int sensor = 0; sensor < activeSensorCount; sensor++) {
    selectPCAChannel(activeChannels[sensor]);

    int16_t rawAx = 0;
    int16_t rawAy = 0;
    int16_t rawAz = 0;

    if (ACQUISITION_MODE == ACQ_MODE_FULL_DIAGNOSTIC) {
      int16_t rawGx = 0;
      int16_t rawGy = 0;
      int16_t rawGz = 0;

      const bool ok =
          readMPU(rawAx, rawAy, rawAz, rawGx, rawGy, rawGz);

      // Acceleration is intentionally kept close to the sensor
      // measurement. Gravity/DC removal is performed in the PC analysis.
      const int16_t ax = ok ? rawAx : 0;
      const int16_t ay = ok ? rawAy : 0;
      const int16_t az = ok ? rawAz : 0;

      // Remove only stationary gyro zero-rate bias.
      const int16_t gx =
          ok ? clampToInt16(rawGx - gyroOffsets[sensor].gx) : 0;
      const int16_t gy =
          ok ? clampToInt16(rawGy - gyroOffsets[sensor].gy) : 0;
      const int16_t gz =
          ok ? clampToInt16(rawGz - gyroOffsets[sensor].gz) : 0;

      appendI16(payload, idx, ax);
      appendI16(payload, idx, ay);
      appendI16(payload, idx, az);
      appendI16(payload, idx, gx);
      appendI16(payload, idx, gy);
      appendI16(payload, idx, gz);
    } else {
      const bool ok = readAccelOnly(rawAx, rawAy, rawAz);

      const int16_t ax = ok ? rawAx : 0;
      const int16_t ay = ok ? rawAy : 0;
      const int16_t az = ok ? rawAz : 0;

      appendI16(payload, idx, ax);
      appendI16(payload, idx, ay);
      appendI16(payload, idx, az);
    }
  }

  sendFrame(PACKET_TYPE_DATA, payload, idx);
}

// ============================================================
// ARDUINO SETUP / LOOP
// ============================================================
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
void loop() {
  // Rational microsecond scheduler, generic to whatever SAMPLE_RATE_HZ is
  // currently set to. Distributes the fractional remainder across
  // successive samples so the long-term average rate is exact, without
  // truncating the period to an integer microsecond value.
  static uint32_t nextSampleUs = micros();
  static uint32_t remainderAccumulator = 0;

  const uint32_t now = micros();

  if ((int32_t)(now - nextSampleUs) >= 0) {
    const uint32_t lateness = now - nextSampleUs;

    // If execution is badly delayed, count the event and re-anchor the
    // scheduler. This avoids rapid "catch-up" packets that would corrupt
    // the effective sample spacing.
    if (lateness >= (SAMPLE_PERIOD_BASE_US + 1U)) {
      missedDeadlines++;
      nextSampleUs = now;
      remainderAccumulator = 0;
    }

    sendDataFrame();

    // Add one nominal period.
    nextSampleUs += SAMPLE_PERIOD_BASE_US;

    // Distribute the fractional remainder across successive samples.
    remainderAccumulator += SAMPLE_PERIOD_REMAINDER;
    if (remainderAccumulator >= SAMPLE_RATE_HZ) {
      nextSampleUs += 1U;
      remainderAccumulator -= SAMPLE_RATE_HZ;
    }
  }
}

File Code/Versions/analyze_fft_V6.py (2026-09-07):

# V6 - App-ready FFT/FRF analyzer with fixed 0-240 Hz plot range
# Structural Vibration Analyzer

import argparse
import shutil
from pathlib import Path
from datetime import datetime

import pandas as pd
import numpy as np

import matplotlib
matplotlib.use("Agg")  # safer when launched from the PC app
import matplotlib.pyplot as plt


# ============================================================
# DEFAULT SETTINGS
# ============================================================

DEFAULT_RAW_DATA_DIR = Path(
    r"F:\RLenovo99\Documents\Projects\Structural_Vibration_Analyzer\Data\raw"
)
DEFAULT_PROCESSED_DIR = Path(
    r"F:\RLenovo99\Documents\Projects\Structural_Vibration_Analyzer\Data\processed"
)

DEFAULT_FILE_PATTERN = "esp32_vibration_*.csv"

AXIS_SUFFIXES = ["ax_g", "ay_g", "az_g"]

AXIS_LABELS = {
    "ax_g": "X Axis",
    "ay_g": "Y Axis",
    "az_g": "Z Axis",
}

# "auto" chooses s3 when available; otherwise the highest-numbered
# selected sensor is used as the reference/input sensor.
DEFAULT_REFERENCE_SENSOR = "auto"

NUM_TOP_PEAKS = 10
PEAK_MIN_SPACING_HZ = 2.0

# Fixed display range for FFT/FRF/coherence frequency-domain plots.
# Calculations still use the full available spectrum internally.
PLOT_FREQUENCY_MIN_HZ = 0.0
PLOT_FREQUENCY_MAX_HZ = 240.0

FREQUENCY_BANDS = [
    (0, 10),
    (10, 25),
    (25, 50),
    (50, 100),
    (100, 150),
    (150, 200),
    (200, None),
]

# Default is no artificial amplitude thresholding.
DEFAULT_NOISE_THRESHOLD_G = 0.0

# If timing variation exceeds these limits, FFT/FRF calculations are
# performed on a linearly resampled uniform time grid.
DEFAULT_JITTER_STD_RATIO_LIMIT = 0.01
DEFAULT_MAX_DT_DEVIATION_RATIO = 0.05

# Orientation correction should reflect the actual physical mounting.
# Defaults are intentionally neutral to avoid silently changing phase/sign.
SENSOR_AXIS_SIGN = {
    "s1": {"ax_g": 1, "ay_g": 1, "az_g": 1},
    "s2": {"ax_g": 1, "ay_g": 1, "az_g": 1},
    "s3": {"ax_g": 1, "ay_g": 1, "az_g": 1},
}


# ============================================================
# ARGUMENTS
# ============================================================

def parse_args():
    parser = argparse.ArgumentParser(
        description=(
            "FFT/FRF analyzer for Structural Vibration Analyzer CSV files."
        )
    )

    parser.add_argument(
        "--input",
        default=None,
        help=(
            "Raw CSV file to analyze. If omitted, the script asks "
            "or uses the latest file."
        ),
    )

    parser.add_argument(
        "--raw-dir",
        default=str(DEFAULT_RAW_DATA_DIR),
        help="Folder containing raw CSV files.",
    )

    parser.add_argument(
        "--output-dir",
        default=str(DEFAULT_PROCESSED_DIR),
        help="Folder where processed run folders are saved.",
    )

    parser.add_argument(
        "--file-pattern",
        default=DEFAULT_FILE_PATTERN,
        help="File pattern used when selecting a raw file automatically.",
    )

    parser.add_argument(
        "--num-sensors",
        type=int,
        choices=[1, 2, 3],
        default=None,
        help=(
            "Optional compatibility filter. Analyze only the first N available "
            "logical sensors. If omitted, sensors are detected from the CSV."
        ),
    )

    parser.add_argument(
        "--reference-sensor",
        default=DEFAULT_REFERENCE_SENSOR,
        help=(
            "Reference/input sensor for FRF calculation. "
            "Use s1, s2, s3, or auto. Default: auto."
        ),
    )

    parser.add_argument(
        "--noise-threshold-g",
        type=float,
        default=DEFAULT_NOISE_THRESHOLD_G,
        help=(
            "Optional hard amplitude threshold after mean removal. "
            "Default 0.0 disables thresholding."
        ),
    )

    parser.add_argument(
        "--show-plots",
        action="store_true",
        help=(
            "Show Matplotlib windows. Not recommended when running "
            "from the PC app."
        ),
    )

    return parser.parse_args()


args = parse_args()

RAW_DATA_DIR = Path(args.raw_dir)
PROCESSED_DIR = Path(args.output_dir)
FILE_PATTERN = args.file_pattern

PROCESSED_DIR.mkdir(parents=True, exist_ok=True)


# ============================================================
# SELECT RAW CSV FILE
# ============================================================

def select_csv_file():
    if args.input:
        input_path = Path(args.input)

        if not input_path.exists():
            raise FileNotFoundError(
                f"Input CSV file not found: {input_path}"
            )

        return input_path

    csv_files = sorted(RAW_DATA_DIR.glob(FILE_PATTERN))

    if not csv_files:
        raise FileNotFoundError(
            f"No ESP32 vibration CSV files found in: {RAW_DATA_DIR}"
        )

    print("\nAvailable raw data files:\n", flush=True)

    for i, file in enumerate(csv_files, start=1):
        print(f"{i}. {file.name}", flush=True)

    choice = input(
        "\nEnter the file number to analyze, "
        "or press ENTER to use the latest file: "
    ).strip()

    if choice == "":
        return max(csv_files, key=lambda p: p.stat().st_mtime)

    try:
        selected_index = int(choice) - 1
        return csv_files[selected_index]
    except (ValueError, IndexError):
        raise ValueError(
            "Invalid selection. Please enter a valid file number."
        )


CSV_FILE = select_csv_file()

print(f"\nAnalyzing:\n{CSV_FILE}", flush=True)


# ============================================================
# CREATE UNIQUE PROCESSED RUN FOLDER
# ============================================================

raw_stem = CSV_FILE.stem
run_folder = PROCESSED_DIR / f"{raw_stem}_processed_V6"

if run_folder.exists():
    timestamp = datetime.now().strftime("%Y-%m-%d_%H-%M-%S")
    run_folder = (
        PROCESSED_DIR / f"{raw_stem}_processed_V6_{timestamp}"
    )

run_folder.mkdir(parents=True, exist_ok=True)

print(f"\nSaving processed results to:\n{run_folder}", flush=True)


# ============================================================
# LOAD DATA AND DETECT SENSOR COLUMNS
# ============================================================

df = pd.read_csv(CSV_FILE)

legacy_columns = ["ax_g", "ay_g", "az_g"]


def detect_available_sensors(dataframe):
    available = []

    for sensor_number in range(1, 4):
        sensor = f"s{sensor_number}"
        required_columns = [
            f"{sensor}_{axis}" for axis in AXIS_SUFFIXES
        ]

        if all(
            column in dataframe.columns
            for column in required_columns
        ):
            available.append(sensor)

    return available


available_sensors = detect_available_sensors(df)
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

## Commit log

2026-05-11 Create mpu mount.f3d
    [mpu mount.f3d]
2026-05-11 Add Fusion 360 mounting details to README
    Added Fusion 360 section with mounting details.
2026-05-11 Fix typo in README regarding sensor mounting
2026-05-11 updating main scripts to manage multiple sensors
2026-05-11 multiple sensors version upkoaded
2026-05-12 main_V0 corrected and 3 sensor runs added
    [main_V0.cpp]
2026-08-31 CEN DEVELOP APP UPDATES
    CHANGES MADE WHILE IMPROVING/DEVELOPING THE ANALYZER
    [Structural_Vibration_Analyzer.kicad_pcb, Structural_Vibration_Analyzer.kicad_sch]
